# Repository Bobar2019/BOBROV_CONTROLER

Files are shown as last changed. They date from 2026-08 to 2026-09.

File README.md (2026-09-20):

# BOB-CONTROL — Firmware ESP32-S3 pour ROV



Firmware temps réel embarqué sur **ESP32-S3** pour le contrôle basse couche du sous-marin **BOB-ROV**.

## Matériel

- **MCU :** ESP32-S3 (PlatformIO, Arduino Core, FreeRTOS)
- **IMU :** BNO085 (`0x4A`) via Adafruit BNO08x (protocole SH-2 — Rotation Vector 9-DOF, montage remappé à la source)
- **PWM :** PCA9685 (16 canaux, 50 Hz)
- **Propulseurs :** 8 × ESC brushless (M1-M4 horizontaux, M5-M8 verticaux)
- **Capteurs :** 3 × INA226 (wattmètres), MS5803/MS5837 (pression/profondeur)
- **Liaison :** RPi 5 via USB-CDC natif ou UART GPIO (921 600 bauds)

## Fonctionnalités

- **Protocole binaire** RPi 5 ↔ ESP32-S3 avec CRC16-CCITT et watchdog failsafe
- **Assistances superposables** (masque de bits, protocole v1.4.0) avec PID 4 axes et mixage différentiel :
  - `0x01` **Auto R/T** — Stabilisation PID du roulis et du tangage sur M5-M8
  - `0x02` **Tenue de Profondeur** — PID altitude (profondeur capturée à l'activation)
  - `0x04` **Auto Cap** — PID lacet sur M1-M4 (cap capturé à l'activation)
  - `0x08` **Retour Surface** — Prioritaire : verticaux vers la surface
  - Combinaisons libres (ex. `0x03` = Auto R/T + profondeur ; `0x07` ≡ ancien AUTO FULL) ; le champ `status` de la télémétrie confirme les boucles réellement actives
- **Interface Web embarquée** (LittleFS) avec portail captif automatique
- **WebSocket temps réel** : télémétrie IMU, pression, PWM, puissance (20 Hz)
- **API REST** : configuration Wi-Fi, I2C, PID, mode série
- **Instruments aviation** : horizon artificiel + HSI (Canvas 2D, lissage LERP)
- **Modèle 3D temps réel** : ROV animé par l'IMU (three.js r128 local, GLB servi depuis LittleFS)
- **Mode Témoin (Dry-Run)** : sorties physiques neutralisées pour banc de test
- **Gestion de priorité** : RPi 5 maître absolu < 1s, sinon bascule Web ESP32

## Build & Flash

```bash
# Compiler
pio run

# Téléverser firmware
pio run -t upload

# Téléverser fichiers Web (LittleFS)
pio run -t uploadfs

# Moniteur série debug
pio device monitor -b 115200
```

## Accès Interface Web

Connectez-vous au point d'accès Wi-Fi **BOB-CONTROL_AP** (mot de passe : `bobrov2026`), puis ouvrez `http://192.168.4.1`.

## Documentation

- [PROTOCOLE_RPI5.md](PROTOCOLE_RPI5.md) — protocole série RPi 5 ↔ ESP32-S3 : trames octet par octet, sémantique des statuts, exemple Python prêt à l'emploi, vecteurs de test.
- [BOBCONTROL.md](BOBCONTROL.md) pour la spécification complète (protocole série, architecture, brochage, API).

## Licence

MIT

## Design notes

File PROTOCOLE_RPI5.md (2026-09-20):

# Protocole de Communication Série — BOB-CONTROL ↔ Raspberry Pi 5

**Auteur :** DERO DIDIER — [ddero2014@gmail.com](mailto:ddero2014@gmail.com)
**Cible :** Cockpit RPi 5 (BOB-ROV) — développement Python / pyserial
**Objet :** Spécification complète du lien binaire série entre le Raspberry Pi 5 et le firmware **BOB-CONTROL** (ESP32-S3). Ce document contient tout le nécessaire pour écrire le code côté RPi 5 sans jamais ouvrir le firmware : format des trames octet par octet, sémantique exacte des champs, comportements de sécurité, exemple Python prêt à l'emploi et vecteurs de test.

---

## 1. Vue d'ensemble

| Élément | Valeur |
| :--- | :--- |
| Topologie | Liaison point à point RPi 5 ↔ ESP32-S3 (full-duplex) |
| Débit | **921 600 bauds**, 8 bits, sans parité, 1 stop (8N1) |
| Trames | **Tailles fixes** — descendante : **40 octets** ; montantes : **73 octets** (télémétrie) et **27 octets** (configuration des noms, §5.6) |
| Intégrité | **CRC16-CCITT-FALSE** (polynôme `0x1021`, init `0xFFFF`) sur chaque trame |
| Trame descendante | 20–50 Hz recommandé (commande : masque d'assistances, armement, 16 consignes PWM, masque GPIO ON/OFF) |
| Trame montante | **100 Hz fixe** (télémétrie : IMU, pression, température, puissance, PWM, état des sorties ON/OFF) |
| Synchronisation | Requête descendante `0xFF` (§4.4) ⇒ l'ESP32 renvoie les **noms personnalisés** des sorties (rafale de 10 trames de **27 octets**, §5.6). Aussi poussée automatiquement à la première commande reçue après (re)connexion, et après chaque modification via l'interface Web |
| Sorties ON/OFF | 4 sorties numériques (GPIO 15/16/17/18 par défaut) pilotées par `gpio_cmd`, état réel dans `gpio_state` — forcées à OFF sur watchdog ou E-Stop |
| Failsafe | Watchdog **500 ms** par défaut : perte de liaison ⇒ tous les actionneurs à leur position de sécurité + 4 sorties ON/OFF à OFF |
| Endianness | Tous les champs multi-octets en **little-endian**, **sauf le CRC** (big-endian) |

**Principe de fonctionnement côté RPi 5 :** le Pi envoie en continu des trames de commande (au moins toutes les 400 ms pour ne pas déclencher le watchdog) et lit en continu les trames de télémétrie qui arrivent à 100 Hz. Le firmware applique les consignes, ou bascule automatiquement en sécurité si le flux s'interrompt.

---

## 2. Liaison physique — deux interfaces au choix

Le firmware embarque **deux interfaces physiques** pour le protocole binaire. Le choix se fait dans l'onglet **Paramètres** de l'interface Web de l'ESP32 et est mémorisé en NVS (**redémarrage nécessaire** après changement).

| Mode | Côté ESP32-S3 | Côté RPi 5 | Particularités |
| :--- | :--- | :--- | :--- |
| **USB-CDC Natif** (défaut) | Port USB-C | `/dev/ttyACM0` | Le debug texte du firmware **partage le même port** : la télémétrie binaire est entrecoupée de messages `[SERIAL]`, `[SENSORS]`… Le parseur doit être tolérant (voir §7) ou filtrer sur les en-têtes. |
| **UART Matériel** | `Serial1` — RX : **GPIO 1**, TX : **GPIO 2** | `/dev/serial0` (ou `/dev/ttyAMA0`) | Lien dédié, **propre** (aucun texte parasite). Câblage croisé obligatoire : TX du Pi → GPIO 1, GPIO 2 → RX du Pi. Référence commune (GND) indispensable. |

> **Note RPi 5 (mode UART) :** activer l'UART matériel via `raspi-config` → *Interface Options* → *Serial Port* : **login shell = NON**, **matériel série = OUI**. Vérifier aussi que `/boot/firmware/config.txt` contient `enable_uart=1`.
>
> **Permissions :** ajouter l'utilisateur au groupe `dialout` (`sudo usermod -aG dialout $USER`, puis reconnexion) pour accéder au port sans `sudo`.

---

## 3. Cadre général des trames

### 3.1 En-têtes et sens de circulation

| Sens | En-tête (2 octets) | Type (offset 2) | Taille totale |
| :--- | :--- | :--- | :--- |
| RPi 5 → ESP32-S3 (descendante) | `0xAA` `0x55` | `0x01` | **40 octets** |
| RPi 5 → ESP32-S3 (descendante) | `0xAA` `0x55` | `0xFF` | **40 octets** — requête de synchronisation, contenu ignoré (§4.4) |
| ESP32-S3 → RPi 5 (montante) | `0x55` `0xAA` | `0x02` | **73 octets** |
| ESP32-S3 → RPi 5 (montante) | `0x55` `0xAA` | `0x03` | **27 octets** — nom d'un canal PWM auxiliaire 10–15 (§5.6) |
| ESP32-S3 → RPi 5 (montante) | `0x55` `0xAA` | `0x04` | **27 octets** — nom d'une sortie tout-ou-rien 1–4 (§5.6) |

Les en-têtes ont des motifs **opposés** (`AA 55` vs `55 AA`) : un simple `find` sur la séquence correcte suffit à se resynchroniser dans un flux bruité.

### 3.2 CRC16-CCITT-FALSE

Le CRC couvre les octets **de l'offset 2 jusqu'à l'avant-dernier octet de la trame** (le champ CRC lui-même est exclu) :

| Trame | Octets couverts par le CRC | CRC stocké aux offsets |
| :--- | :--- | :--- |
| Descendante (40 octets) | `[2..37]` | `[38]` = octet **fort**, `[39]` = octet **faible** |
| Montante (73 octets) | `[2..70]` | `[71]` = octet **fort**, `[72]` = octet **faible** |
| Configuration des noms (27 octets) | `[2..24]` | `[25]` = octet **fort**, `[26]` = octet **faible** |

Paramètres : polynôme `0x1021`, valeur initiale `0xFFFF`, ni réflexion d'entrée/sortie, ni XOR final.
**Valeur de contrôle** : `crc16_ccitt(b"123456789") == 0x29B1`.

> **⚠️ Le CRC est stocké en big-endian** (octet fort d'abord), contrairement à **tous** les autres champs multi-octets de la trame qui sont en little-endian. C'est la source d'erreur n°1 des implémentations tierces — voir l'exemple validé §7.

### 3.3 Résynchronisation

Une trame descendante invalide (CRC KO) est **silencieusement ignorée** par le firmware : la machine à états repart en attente d'en-tête. Côté RPi 5, appliquer la même stratégie : chercher `0x55 0xAA`, tenter de décoder la trame, en cas de CRC invalide **avancer d'un seul octet** et recommencer (jamais sauter la trame d'un bloc).

**Depuis la v1.5.0, la trame montante n'a plus une taille unique** : la longueur attendue se déduit du **type à l'offset 2** — `0x02` ⇒ 73 octets, `0x03`/`0x04` ⇒ 27 octets, tout autre octet ⇒ faux en-tête, avancer d'un octet (voir la classe `UplinkReader` du §7).

---

## 4. Trame descendante — RPi 5 → ESP32-S3 (40 octets)

Format : `[0xAA][0x55][TYPE][MODE][ARM][PWM_0..15][GPIO_CMD][CRC_HI][CRC_LO]`

| Offset | Taille | Champ | Type | Valeurs | Description |
| ---: | ---: | :--- | :--- | :--- | :--- |
| 0 | 1 | `header1` | `uint8_t` | `0xAA` | En-tête 1 |
| 1 | 1 | `header2` | `uint8_t` | `0x55` | En-tête 2 |
| 2 | 1 | `type` | `uint8_t` | `0x01` | Type « commande » |
| 3 | 1 | `mode` | `uint8_t` | masque de bits | **Masque d'assistances superposables** (v1.4.0) — chaque bit active une boucle indépendante : bit 0 (`0x01`) = Auto Roulis/Tangage, bit 1 (`0x02`) = Tenue de Profondeur, bit 2 (`0x04`) = Auto Cap (Yaw), bit 3 (`0x08`) = Retour Surface (**prioritaire**). `0x00` = Passif (manuel direct). Exemple : `0x03` = Auto R/T + Tenue de Profondeur. Bits 4–7 ignorés. |
| 4 | 1 | `arm_state` | `uint8_t` | `0` `1` `2` | **0** = Désarmé, **1** = Armé, **2** = E-Stop (arrêt d'urgence) |
| 5 | 32 | `pwm[0..15]` | `uint16_t` × 16 (LE) | 1000–2000 | Consignes en **µs**. `pwm[k]` occupe les offsets `5 + 2k` (octet faible d'abord) : `pwm[0]` @ 5–6 … `pwm[15]` @ 35–36. Neutre : **1500**. Le firmware borne toute valeur à 1000–2000 µs. |
| 37 | 1 | `gpio_cmd` | `uint8_t` | masque 4 bits | Commandes des 4 sorties tout-ou-rien : **bit 0 = sortie 1** … **bit 3 = sortie 4** (1 = ON, 0 = OFF). Bits 4–7 ignorés. Les sorties sont pilotables **même désarmé** (auxiliaires) ; neutralisées à OFF par l'E-Stop et le watchdog. |
| 38 | 1 | `crc16_hi` | `uint8_t` | — | CRC16 (voir §3.2) — octet fort |
| 39 | 1 | `crc16_lo` | `uint8_t` | — | CRC16 — octet faible |

> **Composition des assistances (v1.4.0) :** le champ `mode` est un masque — les boucles PID se superposent librement (ex. `0x03` = Auto R/T + tenue de profondeur). À l'activation d'une tenue, la consigne est capturée sur place : **profondeur courante** pour le bit 1, **cap courant** pour le bit 2. Le **bit 3 (Retour Surface) est prioritaire** : il suspend l'Auto R/T et la tenue de profondeur et force les moteurs verticaux M5–M8 vers la surface (≈ 1700 µs) ; l'Auto Cap (bit 2) reste actif sur les horizontaux M1–M4.

### 4.1 Affectation des 16 canaux

| Canal | Actionneur | Plage utile | Neutre / repos |
| :--- | :--- | :--- | :--- |
| 0–7 | ESC propulseurs M1–M8 (M1–M4 horizontaux, M5–M8 verticaux) | 1000–2000 µs | 1500 µs |
| 8–9 | Servomoteurs Pan & Tilt caméra | 1000–2000 µs | 1500 µs |
| 10–11 | Pince / rotation d'outil | 1000–2000 µs | 1500 µs |
| 12–13 | Gradateurs MOSFET projecteurs LED | 1000 µs = 0 % → 2000 µs = 100 % | 1000 µs (0 %) |
| 14–15 | Canaux auxiliaires / extensions | 1000–2000 µs | 1500 µs |

> **Depuis le protocole v1.1.0**, les canaux 10 à 15 sont **typables individuellement** (Bidirectionnel / Unidirectionnel), configurables dans l'onglet Paramètres de l'interface Web et persistés en NVS — voir §4.3.

### 4.2 Cadence et comportement d'émission

* **Envoyer en continu**, même quand rien ne change : c'est ce flux qui alimente le watchdog (§6.1) et le statut « maître » (§6.3).
* Cadence recommandée : **20 à 50 trames/s** (une trame toutes les 20–50 ms). À 100 Hz, aucune contre-indication technique, seulement de la bande passante inutile.
* En cas de coupure, le failsafe s'active après le **timeout watchdog (500 ms par défaut)** : prévoir un envoi toutes les 400 ms *au pire* si l'application est chargée.

### 4.3 Typage des canaux 10–15 (Bidirectionnel / Unidirectionnel)

Chaque canal 10 à 15 est configurable **individuellement** depuis l'onglet Paramètres de l'interface Web (ressource NVS, appliqué à chaud — aucun redémarrage requis) :

| Type | Plage des consignes | Position de sécurité (failsafe / E-Stop / watchdog) |
| :--- | :--- | :--- |
| **Bidirectionnel** | 1000–2000 µs, neutre 1500 µs | **1500 µs** |
| **Unidirectionnel** (pleine échelle) | 1000 µs = 0 % → 2000 µs = 100 % | **1000 µs (0 %)** |

Configuration par défaut : CH10/11 (pinces/outils) et CH14/15 (auxiliaires) en **Bidirectionnel**, CH12/13 (gradateurs LED) en **Unidirectionnel**. Le firmware borne toujours les consignes à 1000–2000 µs quel que soit le type ; le type ne change que la **position de sécurité** appliquée par le failsafe (et l'affichage côté interface Web).

### 4.4 Requête de synchronisation — type `0xFF` (v1.5.0)

Trame descendante de **40 octets** au **format identique** à la commande standard (§4) — seul le champ `type` vaut `0xFF`. **Tout le contenu (offsets 3 à 37) est ignoré** : envoyer des zéros suffit (CRC calculé normalement sur `[2..37]`).

Effets à la réception côté firmware :

* l'ESP32 renvoie immédiatement les **noms personnalisés** des sorties (rafale de trames montantes `0x03`/`0x04`, §5.6) — **sans modifier** les consignes en cours (PWM, GPIO, armement) ;
* la trame **réarme le watchdog** (elle vaut preuve de liaison, comme une commande valide) et efface le bit `0x08` de la télémétrie.

**À envoyer par le cockpit :**

1. **au démarrage** (avant la première trame de commande) — le cockpit récupère les libellés des sorties avant d'afficher quoi que ce soit ;
2. après toute **reprise de liaison** — en pratique redondant : le firmware resynchronise déjà automatiquement à la première commande reçue après (re)connexion (§5.6.2), mais l'envoi explicite est inoffensif.

> Le firmware renvoie **toujours la configuration complète** (6 canaux PWM + 4 sorties TOR, 10 trames), que des noms soient personnalisés ou non : une trame à `name_len = 0` signifie « nom par défaut » — le RPi 5 applique alors son propre libellé.

---

## 5. Trame montante — ESP32-S3 → RPi 5 (73 octets)

Format : `[0x55][0xAA][TYPE][STATUS][QUAT][GYRO][PRESS][TEMP][POWER×6][PWM_ACT×16][GPIO_STATE][CRC]`

Émise **en continu à 100 Hz** (toutes les 10 ms) dès que le firmware a démarré.

| Offset | Taille | Champ | Type | Facteur de conversion | Description |
| ---: | ---: | :--- | :--- | :--- | :--- |
| 0 | 1 | `header1` | `uint8_t` | — | `0x55` |
| 1 | 1 | `header2` | `uint8_t` | — | `0xAA` |
| 2 | 1 | `type` | `uint8_t` | — | `0x02` (télémétrie) |
| 3 | 1 | `status` | `uint8_t` | bits — voir §5.1 | État du système |
| 4 | 8 | `quat[4]` | `int16_t` × 4 (LE) | **÷ 10 000** | Quaternion W, X, Y, Z du repère **véhicule** (voir §5.3) |
| 12 | 6 | `gyro[3]` | `int16_t` × 3 (LE) | **÷ 100** → °/s | Vitesses angulaires X, Y, Z du repère véhicule |
| 18 | 4 | `pressure` | `int32_t` (LE) | **÷ 10** → mbar | Pression absolue (ex. 10132 = 1013,2 mbar) |
| 22 | 4 | `temperature` | `int32_t` (LE) | **÷ 100** → °C | Température de l'eau (ex. 2500 = 25,00 °C) |
| 26 | 12 | `power[6]` | `uint16_t` × 6 (LE) | **÷ 1000** → V / A | Énergie propulsion (v1.1.0) : `[V_BAT, rés, signal_H, I_H, signal_V, I_V]` en mV / mA — voir §5.2 |
| 38 | 32 | `pwm_actual[16]` | `uint16_t` × 16 (LE) | µs (entiers) | Consignes PWM courantes. `pwm_actual[k]` occupe les offsets `38 + 2k`. |
| 70 | 1 | `gpio_state` | `uint8_t` | masque 4 bits — voir §5.5 | État **réel relu** des 4 sorties ON/OFF : bit 0 = sortie 1 … bit 3 = sortie 4 (1 = ON) |
| 71 | 2 | `crc16` | `uint16_t` (**BE**) | — | CRC16 sur `[2..70]` — octet fort puis faible |

### 5.1 Sémantique exacte des bits de `status`

| Bit | Masque | Signification réelle (comportement du firmware) |
| :--- | :--- | :--- |
| 0 | `0x01` | Réservé (toujours 0) |
| 1 | `0x02` | **Liaison établie** : positionné dès qu'**au moins une trame descendante valide a été reçue depuis le boot**. ⚠️ Ce n'est **pas** l'état d'armement courant — c'est un témoin de liaison (« le firmware a déjà entendu le RPi 5 »). |
| 2 | `0x04` | **Auto Roulis/Tangage réellement actif** (v1.4.0) : boucle PID roulis + tangage en cours d'exécution — 0 si la boucle est absente du masque ou **suspendue par le retour surface**. |
| 3 | `0x08` | **Watchdog série déclenché** : plus aucune trame descendante valide reçue depuis > timeout (défaut 500 ms). Redescend automatiquement dès qu'une trame valide arrive. |
| 4 | `0x10` | **Dry-run (Mode Témoin)** : sorties physiques PCA9685 neutralisées (les consignes sont mémorisées dans `pwm_actual` mais aucune impulsion n'est émise vers les actionneurs). |
| 5 | `0x20` | **Tenue de Profondeur réellement active** (v1.4.0) : boucle PID altitude en cours d'exécution — 0 si absente du masque ou **suspendue par le retour surface**. |
| 6 | `0x40` | **Auto Cap réellement actif** (v1.4.0) : boucle PID lacet en cours d'exécution (indépendante du retour surface). |
| 7 | `0x80` | **Retour Surface réellement actif** (v1.4.0) : verticaux M5–M8 forcés vers la surface, Roll/Pitch et tenue de profondeur suspendus. |

### 5.2 Détail des 6 mesures de puissance (v1.1.0 — INA3221)

**Sémantique v1.1.0 :** l'INA3221 (triple mesure, `0x40`) remplace le premier INA226 et supervise l'énergie de propulsion. **Le format binaire est inchangé** (mêmes 6 slots mV/mA, mêmes offsets) — seule la sémantique des valeurs change :

| Index `power` | Offset | Mesure | Source (bus I2C n°1) |
| :--- | ---: | :--- | :--- |
| `power[0]` | 26 | **Tension batterie propulsion V_BAT** (mV) | **INA3221** (`0x40`) canal 1 |
| `power[1]` | 28 | Réservé (**0**) | INA3221 canal 1 — pas de shunt sur ce canal |
| `power[2]` | 30 | Signal brut capteur horizontaux (mV) | INA3221 canal 2 — tension ACS770 lue sur IN- |
| `power[3]` | 32 | **Courant propulseurs horizontaux M1–M4** (mA) | **ACS770-100U** via INA3221 canal 2 (40 mV/A) |
| `power[4]` | 34 | Signal brut capteur verticaux (mV) | INA3221 canal 3 — tension ACS770 lue sur IN- |
| `power[5]` | 36 | **Courant propulseurs verticaux M5–M8** (mA) | **ACS770-100U** via INA3221 canal 3 (40 mV/A) |

* Le courant est émis en valeur **absolue** (mA) ; plage utile **±4,09 A** (au-delà, l'ACS770 sature — le firmware le traite comme un défaut de surintensité). Capteur absent ⇒ 0.
* Les champs `power[2]` / `power[4]` (signal brut mV) sont fournis pour diagnostic — le firmware applique déjà la conversion en Ampères dans `power[3]` / `power[5]`.
* Les deux **INA226 résiduels** (#2 Aux/LEDs `0x44`, #3 `0x45`) ne transitent **pas** dans la trame série : ils restent visibles uniquement dans la télémétrie WebSocket de l'interface Web embarquée (`power[3]` / `power[4]` du JSON).
* Ancienne sémantique (firmware ≤ v1.0.1) : `[V,I]` du Pi, Aux et Moteurs — un récepteur ignorant la version décodait 3 wattmètres.

### 5.3 Repère IMU et conversions complémentaires

Le quaternion et le gyroscope sont exprimés dans le **repère véhicule** (NED : **X = avant**, **Y = droite**, **Z = bas**), montage du BNO085 déjà compensé par le firmware. Le quaternion est **unitaire** : `w² + x² + y² + z² = 1` (tolérance numérique).

Conversions utiles pour l'affichage (formules identiques à celles du firmware) :

\[
\begin{aligned}
\text{roll} &= \operatorname{atan2}\big(2(wx+yz),\; 1-2(x^2+y^2)\big) \\
\text{pitch} &= \operatorname{asin}\big(2(wy-zx)\big) \\
\text{cap} &= -\operatorname{atan2}\big(2(wz+xy),\; 1-2(y^2+z^2)\big)
\end{aligned}
\]

Angles en radians, cap positif dans le sens **horaire** (nord → est). Normaliser le cap dans \([-180°, +180°]\) ou \([0°, 360°]\) selon usage.

Profondeur (le firmware n'envoie que la pression absolue ; à convertir côté RPi 5) :

* **Profondeur eau douce (m)** : \(h = \Delta P_{mbar} \times 100 / (\rho \cdot g) \approx \Delta P_{mbar} \times 0{,}010194\) avec \(\Delta P = P - P_{surface}\), \(\rho = 1000\ \text{kg/m}^3\), \(g = 9{,}81\ \text{m/s}^2\).
* **Altitude barométrique (m, hors de l'eau)** : \(h = 44330 \times \left(1 - (P/P_0)^{0,190284}\right)\) avec \(P_0 = 1013{,}25\) mbar (à adapter à la pression du jour).
* La référence surface \(P_{surface}\) se capture **capteur hors de l'eau au démarrage** — c'est à l'application RPi 5 de mémoriser sa propre tare (les données brutes reçues restent absolues).

### 5.4 `pwm_actual` — consignes vs sorties physiques

`pwm_actual` reflète **les consignes courantes appliquées au contrôleur PWM** (après clamp 1000–2000 µs et, en mode AUTO, après corrections PID et mixage) — et non l'état électrique des sorties :

* Si `status & 0x10` (**dry-run**) : les valeurs affichées sont mémorisées mais **aucune sortie physique** n'est pilotée (le PCA9685 reste au neutre).
* Si `status & 0x08` (**watchdog**) : les sorties ont été forcées à leur position de sécurité ; `pwm_actual` peut encore montrer les dernières consignes jusqu'à la trame suivante.

### 5.5 `gpio_state` — état réel des 4 sorties ON/OFF

`gpio_state` reflète l'état **physiquement relu** des 4 sorties tout-ou-rien (niveau des broches après écriture) — et non la dernière commande reçue. Si `gpio_cmd` (trame descendante) et `gpio_state` diffèrent durablement, la commande n'a pas pu être appliquée.

* **Watchdog déclenché** (`status & 0x08`) : les 4 sorties sont forcées **à OFF** ⇒ `gpio_state = 0x00`.
* **E-Stop** (`arm_state = 2`) : idem, `gpio_state = 0x00`.
* Les broches sont assignées par défaut à **GPIO 15/16/17/18** (reconfigurables dans l'onglet Paramètres de l'interface Web, appliquées au redémarrage) et initialisées **à OFF** au boot.
* Les sorties ON/OFF sont indépendantes du **dry-run** (§6.4) : le dry-run ne concerne que les sorties PWM/PCA9685.

### 5.6 Trames de configuration des noms — types `0x03` / `0x04` (v1.5.0)

**Source unique de vérité :** l'ESP32-S3 détient les **noms personnalisés** des sorties (saisis dans l'interface Web, persistés en NVS) et les transmet au RPi 5 — le cockpit n'a **aucune valeur codée en dur** : il affiche les libellés reçus, ou son propre libellé par défaut quand `name_len = 0`.

#### 5.6.1 Format — 27 octets par sortie

Format : `[0x55][0xAA][TYPE][ID][LEN][NAME ×20][CRC_HI][CRC_LO]`

| Offset | Taille | Champ | Type | Valeurs | Description |
| ---: | ---: | :--- | :--- | :--- | :--- |
| 0 | 1 | `header1` | `uint8_t` | `0x55` | En-tête 1 |
| 1 | 1 | `header2` | `uint8_t` | `0xAA` | En-tête 2 |
| 2 | 1 | `type` | `uint8_t` | `0x03` `0x04` | `0x03` = nom d'un canal PWM auxiliaire (10–15) ; `0x04` = nom d'une sortie tout-ou-rien |
| 3 | 1 | `id` | `uint8_t` | 10–15 / 1–4 | Numéro de **canal PWM** (`0x03`) ou de **sortie TOR** (`0x04`) — voir §5.6.3 |
| 4 | 1 | `name_len` | `uint8_t` | 0–20 | Longueur **utile** du nom en octets UTF-8. **0 = nom par défaut** (le RPi 5 applique son libellé par défaut) |
| 5 | 20 | `name` | `char[20]` | UTF-8 | Nom, complété par des `0x00` au-delà de `name_len` — lire exactement `name_len` octets |
| 25 | 1 | `crc16_hi` | `uint8_t` | — | CRC16 sur `[2..24]` — octet **fort** |
| 26 | 1 | `crc16_lo` | `uint8_t` | — | CRC16 — octet **faible** |

#### 5.6.2 Déclencheurs d'envoi (comportement du firmware)

Les **10 trames** (6 PWM + 4 TOR) sont émises en **rafale lissée** : **une trame par cycle de télémétrie (10 ms)**, intercalée entre deux trames `0x02` complètes — la cadence de télémétrie **100 Hz reste intacte**. La rafale complète s'étale sur ~100 ms.

| Déclencheur | Quand |
| :--- | :--- |
| **Requête `0xFF`** | À réception de la trame descendante `0xFF` (§4.4) — cas nominal au démarrage du cockpit |
| **Première commande après (re)connexion** | À la première trame `0x01` valide reçue après le boot de l'ESP32 **ou** après un déclenchement du watchdog — le cockpit reçoit les noms même s'il n'émet jamais de requête `0xFF` |
| **Modification dans l'interface Web** | À chaque sauvegarde des noms (`POST /api/names`) — mise à jour du cockpit en temps réel, sans redémarrage |

#### 5.6.3 Sémantique des `id`

| `type` | `id` | Sortie concernée |
| :--- | :--- | :--- |
| `0x03` | 10–15 | Canaux PWM auxiliaires 10 à 15 (pinces/outils, gradateurs, auxiliaires — voir §4.1) |
| `0x04` | 1–4 | Sorties tout-ou-rien 1 à 4 (**id = bit + 1**, cohérent avec `gpio_cmd`/`gpio_state` §4/§5.5) |

Les canaux **0 à 9** (propulseurs M1–M8, servos caméra) ne sont **pas** transmis : ce sont des affectations fixes du véhicule.

#### 5.6.4 Traitement recommandé côté RPi 5

* **Au démarrage** : envoyer `build_sync_request()` (§7), puis émettre les commandes normales ; attendre la rafale (~100 ms) avant d'afficher les libellés.
* **À chaud** : chaque trame `0x03`/`0x04` remplace le libellé de la sortie `id` — appliquer immédiatement, sans redémarrer.
* `name_len = 0` ⇒ appliquer votre libellé par défaut. Nota : le **pilotage** utilise toujours `id`/masques (`gpio_cmd`, index PWM) — jamais le nom `name`.

---

## 6. Comportements du firmware (règles de sécurité et de priorité)

### 6.1 Watchdog série — failsafe 500 ms

* Le firmware attend **au moins une trame descendante valide** dans une fenêtre de **500 ms** (défaut, réglable 100 ms–plusieurs s dans l'onglet Paramètres via NVS — clé `serial_timeout`).
* Dépassement ⇒ **tous les canaux PWM forcés à leur position de sécurité** (1500 µs pour les bidirectionnels, 1000 µs / 0 % pour les unidirectionnels) et **les 4 sorties ON/OFF forcées à OFF** (`gpio_state = 0x00`). Bit `0x08` positionné dans la télémétrie.
* Dès qu'une trame valide arrive : le watchdog est réarmé, le bit `0x08` disparaît, et **les consignes de cette trame sont appliquées au cycle suivant (≤ 10 ms)**.
* Au démarrage du firmware : le watchdog **ne se déclenche pas** tant qu'aucune trame n'a jamais été reçue (les sorties restent de toute façon en dry-run/neutre par défaut).

### 6.2 États d'armement (champ `arm_state`)

| `arm_state` | Effet immédiat à la réception de CHAQUE trame |
| :--- | :--- |
| **0 — Désarmé** | Canaux **0–7 forcés au neutre** (1500 µs). Canaux **8–15 acceptés tels quels** (pan/tilt, pince, gradateurs utilisables désarmé). Les **4 sorties ON/OFF restent pilotables** (`gpio_cmd` appliqué — auxiliaires utilisables désarmé). Reset des PID. |
| **1 — Armé** | **Les 16 canaux** sont appliqués (`pwm[0..15]`) ainsi que le **masque `gpio_cmd`**. Le **masque d'assistances** est appliqué (superposition Auto R/T, tenue de profondeur, Auto Cap, retour surface). Le contrôleur de vol considère le RPi 5 comme maître. |
| **2 — E-Stop** | **Tous** les canaux à leur position de sécurité (1500 µs / 0 %) + **les 4 sorties ON/OFF forcées à OFF** + reset des PID. Priorité absolue, appliqué à chaque trame reçue. |

> **Point opérationnel :** seules les trames **ARMÉES** transmettent le `mode` et rafraîchissent la maîtrise du RPi 5 (§6.3). Pour reprendre la main après un long arrêt, il suffit de renvoyer des trames armées.

### 6.3 Priorité « maître » RPi 5 / interface Web ESP32

* Chaque trame **armée** reçue marque le RPi 5 comme **maître** du contrôleur de vol.
* Après **1000 ms sans trame armée**, le firmware repasse en mode manuel ESP32 (l'interface Web peut alors changer le mode ; journal série : `[FLIGHT] Maître → Manuel ESP32 (timeout RPi 5)`).
* Tant que le RPi 5 est maître, toute commande de mode émise par l'interface Web est **ignorée** (journal : `[FLIGHT] Commande Web ignorée — RPi 5 est maître`).
* Conséquence pratique : **envoyer des trames armées en continu** (c'est le cas nominal à 20–50 Hz) pour rester maître.

### 6.4 Mode Dry-Run (Sorties Matérielles)

Au boot, les sorties physiques sont **neutralisées** (dry-run actif, bit `0x10`). Les consignes reçues sont suivies dans `pwm_actual` mais le PCA9685 n'émet rien. L'activation des sorties réelles se fait **uniquement** depuis l'interface Web (bouton « Sorties Matérielles », WebSocket `{output_enable: true}` ou REST `POST /api/pwm/output-enable`). C'est un garde-fou de banc : le RPi 5 ne peut pas le désactiver à distance.

> **Sorties ON/OFF :** le dry-run ne les concerne pas — les 4 GPIO sont des sorties numériques à part entière, initialisées à OFF au boot puis pilotables par `gpio_cmd` (et forcées à OFF par le watchdog et l'E-Stop, voir §5.5).

### 6.5 Redémarrage automatique du firmware (perte définitive de l'IMU)

Le firmware embarque un **watchdog IMU** dédié au BNO085 (capteur d'attitude, seul sur le bus I2C n°1). Si le flux de quaternions se fige en opération (plongée, longue inactivité), la récupération escalade automatiquement en 3 niveaux :

1. **Reprise douce SH-2** — après 1 s sans quaternion : ré-initialisation logicielle du capteur (réécriture des rapports SH-2) ;
2. **Reset matériel du bus I2C** — si le niveau 1 échoue ou si le contrôleur I2C reste bloqué (`ESP_ERR_INVALID_STATE`) : destruction puis recréation de l'instance `Adafruit_BNO08x`, 9 impulsions SCL + condition STOP (bit-bang), réinitialisation complète de `Wire` ;
3. **Redémarrage contrôlé** — si le capteur (qui **a déjà fonctionné depuis le boot**) ne répond toujours pas après **3 tentatives de niveau 2** ou **8 s sans aucun quaternion** : le firmware force **tous les canaux PWM à leur position de sécurité** (1500 µs, 0 % pour les unidirectionnels), émet un log explicite sur le moniteur série, puis déclenche `esp_restart()` — **redémarrage automatique de l'ESP32**.

**Ce que le RPi 5 doit savoir :**

* **Propulsion au neutre pendant toute la phase de récupération (niveaux 1 & 2)** : dès le 1er échec, les canaux 0-7 sont verrouillés à 1500 µs **à chaque cycle de contrôle** — une consigne armée réappliquée entre deux tentatives ne peut jamais faire repartir la propulsion avec une attitude inconnue. Les canaux 8-15 (servos, pince, gradateurs) restent pilotables.
* **Pendant le redémarrage (~2-3 s)** : la télémétrie est interrompue, **mais les propulseurs restent physiquement au neutre** — le PCA9685 est un générateur autonome qui conserve ses registres pendant le reboot de l'ESP32 (neutre maintenu sans aucune intervention). Les trames descendantes émises pendant cette fenêtre sont simplement perdues.
* **Après le redémarrage** : la télémétrie reprend seule. Le bit **liaison établie (`0x02`) repasse à 0 puis à 1** dès la première trame descendante valide reçue, et les sorties repartent en **dry-run (`0x10` = 1)** — comme à chaque boot, la réactivation des sorties réelles redevient une action manuelle dans l'interface Web.
* **Aucune action spécifique n'est requise côté RPi 5** : continuer à émettre normalement (la cadence 20-50 Hz ré-établit liaison et maîtrise automatiquement).

> **Garde-fou anti-boucle :** ce redémarrage ne se produit que si le capteur **a déjà fourni au moins un quaternion depuis le boot**. Un BNO085 jamais détecté ou jamais fonctionnel au démarrage n'est **jamais** redémarré en boucle : il reste en mode espacé (badge rouge, une tentative complète toutes les 30 s) et la propulsion demeure au neutre par défaut.

---

## 7. Exemple Python complet (validé hors ligne)

Code autonome, sans dépendance autre que **pyserial** (`pip install pyserial`). Toutes les fonctions de décodage ont été vérifiées contre les vecteurs de test du §8.

```python
#!/usr/bin/env python3
"""Cockpit minimal BOB-ROV — liaison binaire avec BOB-CONTROL (ESP32-S3).
Télémétrie 100 Hz + synchronisation des noms de sorties au démarrage."""
import struct
import time
import serial

# ==================== Constantes du protocole ====================

PORT = '/dev/ttyACM0'      # USB-CDC natif  |  UART GPIO : '/dev/serial0'
BAUD = 921600
TX_HZ = 25.0               # cadence descendante recommandée : 20-50 Hz

# Mode = masque d'assistances superposables (v1.4.0) — combiner avec |
MODE_PASSIF = 0x00
MODE_RT, MODE_DEPTH, MODE_CAP, MODE_SURFACE = 0x01, 0x02, 0x04, 0x08

ARM_DISARMED, ARM_ARMED, ARM_ESTOP = 0, 1, 2

STATUS_ARMED, STATUS_RT, STATUS_WDG, STATUS_DRYRUN = 0x02, 0x04, 0x08, 0x10
STATUS_DEPTH, STATUS_CAP, STATUS_SURFACE = 0x20, 0x40, 0x80

# Trames (v1.5.0) : type à l'offset 2 + taille fixe associée
UL_TELEMETRY, UL_CFG_PWM, UL_CFG_GPIO = 0x02, 0x03, 0x04
DL_SYNC = 0xFF             # requête de synchronisation (descendante, 40 octets)
FRAME_SIZES = {UL_TELEMETRY: 73, UL_CFG_PWM: 27, UL_CFG_GPIO: 27}

# ==================== CRC16-CCITT-FALSE ====================

def crc16_ccitt(data: bytes) -> int:
    """CRC16-CCITT-FALSE : poly 0x1021, init 0xFFFF, pas d'inversion.
    Valeur de contrôle : crc16_ccitt(b'123456789') == 0x29B1."""
    crc = 0xFFFF
    for b in data:
        crc ^= b << 8
        for _ in range(8):
            crc = ((crc << 1) ^ 0x1021) & 0xFFFF if (crc & 0x8000) else (crc << 1) & 0xFFFF
    return crc

# ==================== Trame descendante (40 octets) ====================

def build_downlink_frame(mode: int, arm_state: int, pwm_us, gpio_cmd: int = 0) -> bytes:
    """Construit la trame de commande RPi 5 -> ESP32-S3 (40 octets).
    mode : masque d'assistances superposables (MODE_RT | MODE_DEPTH | ...).
    pwm_us : séquence de 16 valeurs en microsecondes (1000-2000).
    gpio_cmd : masque 4 bits des sorties ON/OFF (bit 0 = sortie 1, 1 = ON)."""
    payload = struct.pack('<BBB16HB', 0x01, mode, arm_state, *pwm_us, gpio_cmd)
    crc = crc16_ccitt(payload)                 # CRC sur [2..37]
    return bytes((0xAA, 0x55)) + payload + struct.pack('>H', crc)   # CRC big-endian

def build_sync_request() -> bytes:
    """Requête de synchronisation (40 octets, contenu ignoré par le firmware).
    À envoyer au démarrage du cockpit : l'ESP32 renvoie alors les noms
    personnalisés des sorties (trames montantes 0x03/0x04, voir §5.6)."""
    payload = struct.pack('<B35x', DL_SYNC)    # type 0xFF + 35 octets à zéro
    crc = crc16_ccitt(payload)                 # CRC sur [2..37]
    return bytes((0xAA, 0x55)) + payload + struct.pack('>H', crc)   # CRC big-endian

# ==================== Trame montante (73 octets) ====================

def parse_uplink_frame(frame: bytes) -> dict:
    """Valide et décode une trame de télémétrie (ESP32-S3 -> RPi 5)."""
    if len(frame) != 73:
        raise ValueError(f'trame de {len(frame)} octets (attendu 73)')
    if frame[0] != 0x55 or frame[1] != 0xAA or frame[2] != 0x02:
        raise ValueError('en-tête invalide')
    if (frame[71] << 8 | frame[72]) != crc16_ccitt(frame[2:71]):    # CRC sur [2..70]
        raise ValueError('CRC16 invalide')
    (type_, status, w, x, y, z, gx, gy, gz, pressure, temperature, *rest) = \
        struct.unpack_from('<BB4h3h2i6H16HB', frame, 2)
    return {
        'status': status,
        'armed': bool(status & STATUS_ARMED),      # liaison établie (≥ 1 trame reçue)
        'auto_rt': bool(status & STATUS_RT),       # Auto Roulis/Tangage réellement actif
        'depth_hold': bool(status & STATUS_DEPTH), # tenue de profondeur active
        'cap_hold': bool(status & STATUS_CAP),     # Auto Cap actif
        'surface': bool(status & STATUS_SURFACE),  # retour surface prioritaire actif
        'watchdog': bool(status & STATUS_WDG),
        'dry_run': bool(status & STATUS_DRYRUN),
        'quat': (w / 10000.0, x / 10000.0, y / 10000.0, z / 10000.0),
        'gyro': (gx / 100.0, gy / 100.0, gz / 100.0),          # °/s
        'pressure_mbar': pressure / 10.0,                       # mbar
        'temperature_c': temperature / 100.0,                   # °C
        'power': list(rest[:6]),                                # mV / mA
        'pwm_us': list(rest[6:22]),                             # µs
        'gpio_state': rest[22],                                 # masque réel des 4 sorties ON/OFF
    }

# ==================== Trame de configuration des noms (27 octets) ====================

def parse_config_frame(frame: bytes) -> dict:
    """Valide et décode une trame de configuration des noms (types 0x03/0x04)."""
    if len(frame) != 27:
        raise ValueError(f'trame de {len(frame)} octets (attendu 27)')
    if frame[0] != 0x55 or frame[1] != 0xAA or frame[2] not in (UL_CFG_PWM, UL_CFG_GPIO):
        raise ValueError('en-tête ou type invalide')
    if (frame[25] << 8 | frame[26]) != crc16_ccitt(frame[2:25]):   # CRC sur [2..24]
        raise ValueError('CRC16 invalide')
    name_len = frame[4]
    if name_len > 20:
        raise ValueError('name_len > 20')
    return {
        'kind': 'pwm' if frame[2] == UL_CFG_PWM else 'gpio',
        'id': frame[3],                                            # canal 10-15 | sortie 1-4
        'name': frame[5:5 + name_len].decode('utf-8', errors='replace'),
        'default_name': name_len == 0,                             # → appliquer votre libellé
    }

class UplinkReader:
    """Réassemble les trames montantes (73 ou 27 octets) dans un flux bruité :
    resynchronisation sur 0x55 0xAA, taille déduite du type (offset 2)."""

    def __init__(self):
        self.buf = bytearray()

    def feed(self, data: bytes):
        """Ajoute des octets reçus ; retourne la liste des trames valides (bytes)."""
        self.buf.extend(data)
        frames = []
        while True:
            idx = self.buf.find(b'\x55\xaa')
            if idx < 0:
                del self.buf[:-1]          # conserve au plus 1 octet (préfixe possible)
                break
            del self.buf[:idx]
            if len(self.buf) < 3:
                break
            size = FRAME_SIZES.get(self.buf[2])
            if size is None:               # type inconnu : faux en-tête probable
                del self.buf[:1]
                continue
            if len(self.buf) < size:
                break
            frame = bytes(self.buf[:size])
            if (frame[size - 2] << 8 | frame[size - 1]) == crc16_ccitt(frame[2:size - 2]):
                frames.append(frame)
                del self.buf[:size]
            else:
                del self.buf[:1]           # CRC invalide : avancer d'un octet
        return frames

# ==================== Boucle principale ====================

def main():
    port = serial.Serial(PORT, BAUD, timeout=0)   # lecture non bloquante
    reader = UplinkReader()
    names = {}                                     # libellés reçus de l'ESP32 (v1.5.0)
    pwm = [1500] * 16                              # toutes voies au neutre
    pwm[0] = 1600                                  # exemple : M1 en avant (µs)
    gpio = 0b0000                                  # sorties ON/OFF (bit 0 = sortie 1)

    port.write(build_sync_request())               # demande les noms (trames 0x03/0x04)

    next_tx = time.monotonic()
    try:
        while True:
            now = time.monotonic()
            if now >= next_tx:                     # --- émission descendante 25 Hz ---
                next_tx += 1.0 / TX_HZ
                port.write(build_downlink_frame(MODE_PASSIF, ARM_ARMED, pwm, gpio))

            for frame in reader.feed(port.read(port.in_waiting or 4096)):
                if frame[2] == UL_TELEMETRY:       # --- télémétrie (73 octets) ---
                    t = parse_uplink_frame(frame)
                    print('quat=(%.3f, %.3f, %.3f, %.3f)  P=%.1f mbar  T=%.1f C  '
                          'pwm0=%d  gpio=0x%X  wdg=%s  dry=%s'
                          % (*t['quat'], t['pressure_mbar'], t['temperature_c'],
                             t['pwm_us'][0], t['gpio_state'], t['watchdog'], t['dry_run']))
                else:                              # --- config noms (27 octets) ---
                    c = parse_config_frame(frame)
                    names[(c['kind'], c['id'])] = c['name'] or f"<défaut {c['kind']}{c['id']}>"
                    print('config :', c['kind'], c['id'], '->', names[(c['kind'], c['id'])])
            time.sleep(0.001)
    finally:
        port.close()

if __name__ == '__main__':
    main()
```

---

## 8. Vecteurs de test (à utiliser pour valider votre parseur)

### 8.1 Valeur de contrôle CRC

```python
assert crc16_ccitt(b'123456789') == 0x29B1
```

### 8.2 Trame descendante de référence

`MODE_PASSIF` + `ARM_ARMED` + toutes voies à 1500 µs + `gpio_cmd = 0x05` (sorties 1 et 3 à ON) :

```
AA 55 01 00 01 DC 05 DC 05 DC 05 DC 05 DC 05 DC 05 DC 05 DC 05
DC 05 DC 05 DC 05 DC 05 DC 05 DC 05 DC 05 DC 05 05 30 72
```

* 40 octets. `DC 05` = `0x05DC` = 1500 LE, répété 16 fois. `gpio_cmd = 0x05` à l'offset 37. CRC final `0x3072` (octet fort `0x30` puis `0x72`).
* Génération : `build_downlink_frame(0, 1, [1500]*16, 0x05).hex() == 'aa55010001' + 'dc05'*16 + '05' + '3072'``

### 8.3 Trame montante de référence

Télémétrie à l'équilibre (quaternion identité, 1013,2 mbar, 25,00 °C), `status = 0x12` (liaison + dry-run), canal 0 à 1600 µs, les autres à 1500, `gpio_state = 0x05` (sorties 1 et 3 à ON) :

```
55 AA 02 12 10 27 00 00 00 00 00 00 00 00 00 00
00 00 94 27 00 00 C4 09 00 00 88 13 20 03 E0 2E
2C 01 D0 39 68 5B 40 06 DC 05 DC 05 DC 05 DC 05
DC 05 DC 05 DC 05 DC 05 DC 05 DC 05 DC 05 DC 05
DC 05 DC 05 DC 05 05 B3 01
```

Décodage attendu :

| Champ | Valeur décodée |
| :--- | :--- |
| `status` | `0x12` → liaison établie + dry-run (`watchdog` = 0) |
| `quat` | `(1.0, 0.0, 0.0, 0.0)` |
| `gyro` | `(0.0, 0.0, 0.0)` °/s |
| `pressure_mbar` | `1013.2` |
| `temperature_c` | `25.0` |
| `power` | `[5000, 800, 12000, 300, 14800, 23400]` → sémantique v1.1.0 (valeurs de test arbitraires) : V_BAT 5,0 V, réservé 800, signal H 12,0 V / courant H 0,3 A, signal V 14,8 V / courant V 23,4 A — voir §5.2 |
| `pwm_us` | `[1600, 1500, 1500, …, 1500]` (16 valeurs) |
| `gpio_state` | `0x05` → sorties 1 et 3 à ON (offset 70) |
| CRC | `0xB301` (offset 71 = `0xB3`, offset 72 = `0x01`) |

### 8.4 Test de robustesse du réassemblage

Injecter du bruit texte, couper une trame en deux, insérer un faux en-tête `55 AA 02 00`, puis vérifier que `UplinkReader.feed()` restitue exactement **2 trames valides**. Le code du §7 (classe `UplinkReader`) est conçu pour ce cas : validé sur la séquence `bruit + moitié1`, puis `moitié2 + faux en-tête + trame complète + bruit`.

Le même test avec une **trame de configuration intercalée** (27 octets) entre deux trames de télémétrie doit restituer **3 trames valides** (2× `0x02` + 1× `0x03`/`0x04`) — c'est le cas réel sur le fil dès qu'une synchronisation est en cours.

### 8.5 Trame de configuration PWM de référence — type `0x03`

Canal **11** nommé « Treuil avant » (`name_len = 0x0C` = 12 octets) :

```
55 AA 03 0B 0C 54 72 65 75 69 6C 20 61 76 61 6E
74 00 00 00 00 00 00 00 00 38 54
```

* 27 octets. `id = 0x0B` = canal 11 ; nom `54 72 65 75 69 6C 20 61 76 61 6E 74` = « Treuil avant », complété de `00` (offsets 17–24) ; CRC `0x3854` sur `[2..24]`.
* Vérification :

```python
assert parse_config_frame(bytes.fromhex(
    '55aa030b0c' + '54726575696c206176616e74' + '00' * 8 + '3854')) \
    == {'kind': 'pwm', 'id': 11, 'name': 'Treuil avant', 'default_name': False}
```

### 8.6 Trame de configuration TOR de référence — nom par défaut

Sortie **2** sans nom personnalisé (`name_len = 0` ⇒ le RPi 5 applique son libellé par défaut) :

```
55 AA 04 02 00 00 00 00 00 00 00 00 00 00 00 00
00 00 00 00 00 00 00 00 00 99 EB
```

* 27 octets. `id = 0x02` = sortie 2 ; `name_len = 0` ; CRC `0x99EB`.
* Vérification :

```python
assert parse_config_frame(bytes.fromhex('55aa0402' + '00' * 21 + '99eb')) \
    == {'kind': 'gpio', 'id': 2, 'name': '', 'default_name': True}
```

### 8.7 Requête de synchronisation de référence — type `0xFF`

Trame descendante minimale (contenu à zéro — ignoré par le firmware) :

```
AA 55 FF 00 00 00 00 00 00 00 00 00 00 00 00 00
00 00 00 00 00 00 00 00 00 00 00 00 00 00 00 00
00 00 00 00 00 00 CA 33
```

* 40 octets. `type = 0xFF` à l'offset 2 ; CRC `0xCA33` sur `[2..37]`.
* Vérification :

```python
assert build_sync_request().hex() == 'aa55ff' + '00' * 35 + 'ca33'
```

---

## 9. Dépannage côté RPi 5

| Symptôme | Cause probable / Remède |
| :--- | :--- |
| `PermissionError` à l'ouverture du port | Utilisateur hors groupe `dialout` : `sudo usermod -aG dialout $USER` puis reconnexion. |
| Aucune trame reçue | 1) Interface choisie côté ESP32 (onglet Paramètres : USB-CDC / UART GPIO) ≠ branchement. 2) Baud ≠ **921600**. 3) UART : TX/RX **croisés** et GND commun. 4) UART Pi non activé (`raspi-config`). |
| Trames reçues mais CRC invalide en permanence | Endianness du CRC inversé (le CRC est **big-endian**, cf. §3.2) ou trame décodée sur un mauvais alignement. |
| Texte `[SERIAL] …` entre les trames binaires | Normal en mode **USB-CDC** (debug partagé) : le `UplinkReader` du §7 filtre tout seul. Pour un lien 100 % propre, passer en **UART matériel**. |
| Trames de **39/72 octets** (au lieu de 40/73) | **Firmware antérieur à la v1.1.0** (sans sorties ON/OFF, voir §10.1) : reflasher le firmware (USB ou OTA). Un parseur conforme au présent document rejettera ces trames (CRC décalé d'un octet). |
| Trames de **71 octets** (au lieu de 73) | **Firmware antérieur au correctif historique de taille montante** (voir §10.2) : reflasher. |
| Interruption de télémétrie de ~2-4 s puis reprise avec `dry=True` | **Normal** : redémarrage automatique du watchdog IMU (BNO085 définitivement muet, §6.5). La propulsion est restée au neutre pendant toute l'opération ; réactiver les sorties depuis l'interface Web si nécessaire. |
| `wdg=True`/`dry=True` persistants dans la télémétrie | `wdg` : vérifier que vos trames partent bien toutes les < 500 ms (et CRC valide). `dry` : activer les sorties via l'interface Web (bouton « Sorties Matérielles »). |
| Propulseurs inertes malgré `arm_state = 1` | Dry-run actif (`dry=True`) ou watchdog déclenché. Vérifier `status` dans la télémétrie. |

---

## 10. Notes de version

### 10.1 v1.1.0 — ajout des sorties tout-ou-rien (39/72 → 40/73 octets)

La version 1.1.0 du protocole ajoute les 4 sorties ON/OFF :

* trame descendante : champ `gpio_cmd` à l'offset **37** ⇒ **40 octets**, CRC sur `[2..37]` stocké en `[38]`/`[39]` ;
* trame montante : champ `gpio_state` à l'offset **70** ⇒ **73 octets**, CRC sur `[2..70]` stocké en `[71]`/`[72]`.

Un firmware antérieur (v1.0.0) émet et attend des trames de **39/72 octets** : l'incompatibilité est **binaire et totale** — les deux extrémités (firmware ESP32 et code RPi 5) doivent être mises à jour ensemble. Le firmware actuel embarque des `static_assert` (vérifiés à la compilation) garantissant tailles et offsets.

### 10.2 Correctif historique — trame montante 71 → 72 octets

Un défaut historique affectait la trame montante : la constante de taille valait **71** alors que la structure `UplinkFrame_t` occupait **72** octets. Conséquences pour les firmwares antérieurs à ce correctif :

* trame émise sur le fil : **71 octets** (dernier octet jamais transmis) ;
* CRC calculé sur `[2..68]` et stocké aux offsets **69–70** (au lieu de 71–72 depuis la v1.1.0, voir §10.1) ;
* l'octet de poids fort du canal `pwm_actual[15]` était **écrasé par le CRC**.

Si vous observez des trames de **71 octets** sur le fil, le firmware en place est antérieur à ce correctif : **reflasher** (USB ou OTA depuis l'interface Web). Le firmware actuel émet la trame **conforme à ce document** (73 octets, CRC sur `[2..70]`).

### 10.3 v1.4.0 — mode combinatoire (masque de bits) et confirmations d'assistance

**Tailles et offsets inchangés** (40/73 octets) : seuls les champs `mode` (offset 3, descendante) et `status` (offset 3, montante) changent de sémantique.

* **Descendante** : `mode` n'est plus une valeur énumérée (0, 1, 2) mais un **masque de bits** — bit 0 (`0x01`) Auto R/T, bit 1 (`0x02`) Tenue de Profondeur, bit 2 (`0x04`) Auto Cap, bit 3 (`0x08`) Retour Surface (prioritaire). Les assistances se **superposent** (ex. `0x03` = Auto R/T + Tenue de Profondeur) ; bits 4–7 ignorés (masqués, sans erreur CRC).
* **Montante** : `status` confirme l'activation **réelle et combinée** des boucles au moment de l'émission — bit 2 (`0x04`) Auto R/T, bit 5 (`0x20`) Tenue de Profondeur, bit 6 (`0x40`) Auto Cap, bit 7 (`0x80`) Retour Surface.
* **Sémantique de capture** : l'activation de la tenue de profondeur capture la **profondeur courante** comme consigne (maintien sur place) ; l'activation de l'Auto Cap capture le **cap courant**. Ces consignes sont recapturées à chaque changement de masque.
* ⚠️ **Incompatibilité sémantique** : un code conçu pour l'ancien protocole qui envoie `mode = 2` (ex-Auto Full) n'active plus que la **tenue de profondeur**. L'équivalent de l'ancien Auto Full est désormais `0x07` (R/T + profondeur + cap).

### 10.4 v1.5.0 — synchronisation des noms (source unique de vérité)

**Tailles des trames principales inchangées** (40 descendante / 73 montante) : la v1.5.0 ajoute des types de trames nouveaux — un parseur existant continue de fonctionner (voir compatibilité ci-dessous).

* **Nouvelle trame descendante `0xFF`** — requête de synchronisation (40 octets, contenu ignoré) : le RPi 5 l'envoie au démarrage pour récupérer les noms personnalisés (§4.4). Elle réarme le watchdog et ne modifie aucune consigne.
* **Nouvelles trames montantes `0x03`** (noms des canaux PWM 10–15, `id` = canal) et **`0x04`** (noms des sorties TOR 1–4, `id` = sortie) — **27 octets chacune**, émises une fois par sortie en **rafale lissée** (une trame par cycle de 10 ms, intercalée entre deux télémétries complètes) sur trois déclencheurs : requête `0xFF`, première commande reçue après (re)connexion, ou modification des noms via l'interface Web (§5.6).
* **Compatibilité ascendante** : un ancien parseur qui filtre `type == 0x02` et la taille 73 ignore naturellement les trames `0x03`/`0x04` (la resynchronisation octet par octet retrouve la télémétrie suivante). Il est toutefois **recommandé** d'étendre le lecteur au dispatch par taille (§3.3 / §7) pour exploiter la synchronisation.
* **Compatibilité descendante** : un ancien firmware (avant v1.5.0) qui reçoit une requête `0xFF` la rejette comme type inconnu (CRC valide requis) — sans effet de bord. Le cockpit peut donc émettre la requête inconditionnellement au démarrage.

---

**Auteur :** DERO DIDIER — [ddero2014@gmail.com](mailto:ddero2014@gmail.com)
*Document garanti conforme au firmware BOB-CONTROL — toute modification du protocole (`include/protocol.h`) doit être répercutée ici.*

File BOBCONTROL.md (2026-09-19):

# BOB-CONTROL - Contrôleur Temps Réel ROV

**Version :** 1.3.0  
**Plateforme :** ESP32-S3 (PlatformIO / Arduino Core / FreeRTOS)  
**Auteur :** Didier Dero  
**Projet associé :** BOB-ROV (Cockpit Raspberry Pi 5)  
**Date :** Septembre 2026  

---

## 🎯 Philosophie & Rôle Système

**BOB-CONTROL** est le micrologiciel temps réel dédié à la gestion basse couche du sous-marin **BOB-ROV**. Embarqué sur un **ESP32-S3**, il isole les fonctions critiques de pilotage matériel et d'acquisition de données du système d'exploitation hôte (Raspberry Pi 5).

Il remplit un quadruple rôle :
1. **Acquisition & Fusion Capteurs :** Lecture haute fréquence des deux bus I2C matériels (centrale inertielle BNO085 **seule** sur le bus n°1 ; triple mesure d'énergie INA3221, wattmètres INA226, pression/profondeur MS5837 et contrôleur PWM PCA9685 sur le bus n°2 — chaque module étant re-routable — bus **et** adresse — via le routage Plug & Play v1.3.0).
2. **Contrôleur de Vol PID :** Stabilisation automatique roulis/tangage/cap/profondeur avec mixage différentiel sur les 8 propulseurs.
3. **Génération PWM Matérielle :** Contrôle autonome de 16 canaux PWM indépendants via PCA9685 (8 propulseurs, servos pan/tilt, pince, gradateurs d'éclairage), avec serveur Web/WebSocket autonome et portail captif pour la configuration et le banc de test.
4. **Gestion de Sécurité Propulsion (v1.1.0) :** check des propulseurs au démarrage (après la connexion Wi-Fi, non bloquant), surveillance surintensité continue via ACS770/INA3221, isolation logicielle du moteur en défaut et remontée d'urgence automatique avec les moteurs verticaux restants.

---

## 🏗️ Architecture Matérielle & Adressage

### 1. Périphériques I2C — Deux Bus Matériels

L'ESP32-S3 possède deux contrôleurs I2C indépendants. La répartition ci-dessous est la **configuration câblée de référence** : l'IMU BNO085 est **seule** sur le bus n°1 (son protocole SH-2 ne tolère aucune cohabitation), tous les autres périphériques vivent sur le bus n°2. Chaque module est re-routable dynamiquement — bus **et** adresse I2C (routage Plug & Play v1.3.0, voir section suivante) :

| Composant | Rôle | Adresse I2C | Bus I2C | Description technique |
| :--- | :--- | :--- | :--- | :--- |
| **BNO085** | IMU 9-DOF | `0x4A` | **n°1 (GPIO 10/11)** | **Seul périphérique du bus n°1** (toute cohabitation perturbe le flux SHTP). Fusion inertielle embarquée (protocole SH-2 via Adafruit BNO08x) : Rotation Vector 9-DOF (cap magnétique) + Game Rotation Vector (secours) + gyroscope calibré @ 50 Hz. Monté tourné de 90° (X capteur vers la droite du ROV) : quaternion **et** gyroscope remappés à la source dans le repère véhicule via `BNO085_MOUNT_YAW_DEG` (−90°) |
| **INA3221** | Énergie Propulsion (v1.1.0) | `0x40` | **n°2 (GPIO 12/13)** | Triple mesure : **Ch1** tension batterie V_BAT (`IN1+`), **Ch2/3** courants des propulseurs via capteurs à effet Hall **ACS770-100U** (sortie `VOUT` 0,5–4,5 V câblée sur `IN-` et lue sur le registre de tension bus — `I (A) = (V_bus_mV − 500) / 40`, plage utile 0–100 A ; voir « Mesure d'Énergie »). Pilote maison (moyennage ×16, ≈35 Hz/canal, identifiant fabricant `0x5449` vérifié au boot) |
| **INA226 #2** | Puissance Aux/LEDs | `0x44` | n°2 (GPIO 12/13) | Wattmètre résiduel éventuel — mesure de ligne d'éclairage et accessoires 12V |
| **INA226 #3** | Puissance Moteurs | `0x45` | n°2 (GPIO 12/13) | Wattmètre résiduel éventuel — mesure de ligne de puissance batterie/propulsion principale |
| **MS5803-30BA / MS5837** | Pression & Profondeur | `0x76` | **n°2 (GPIO 12/13)** | Capteur piézorésistif haute résolution étanche, compensation 24-bit (coefficients C1-C6) |
| **PCA9685** | Contrôleur PWM 16 Ch | `0x41` (ex.) | **n°2 (GPIO 12/13)** | Générateur PWM 12 bits autonome (VCC 3.3V, V+ 5V/Servo). **Re-adressé par straps A0–A5** (0x41 ou 0x42) pour cohabiter avec l'INA3221 qui occupe `0x40` sur le même bus |

> **Note — pourquoi deux bus :** le MS5837-30BA branché sur le même bus que le BNO085 perturbait ses lectures SHTP (tempête de NACK, horizon figé) — et plus généralement, toute cohabitation sur le bus de l'IMU. La règle câblée retenue est donc : **l'IMU seule sur le bus n°1**, tous les autres périphériques sur le bus n°2. Bus n°1 `Wire` (GPIO 10/11, configurables en NVS) et bus n°2 `Wire1` (GPIO 12/13, configurables en NVS). Chaque bus possède ses propres résistances de pull-up (4,7 kΩ vers 3V3). Depuis la v1.3.0, la répartition « quel module vit sur quel bus » **et l'adresse I2C de chaque module** ne sont plus codées en dur : elles sont **routées dynamiquement** (Plug & Play, voir ci-dessous).

**Schéma de câblage des deux bus I2C :**

```
               ┌──────────────────────────┐
               │        ESP32-S3          │
               └──────┬────────────┬──────┘
                      │            │
   ┌──────────────────┴───────┐  ┌─┴────────────────────────────────────────┐
   │ Bus n°1 — « Wire »       │  │ Bus n°2 — « Wire1 »                      │
   │ SDA GPIO 10 / SCL GPIO 11│  │ SDA GPIO 12 / SCL GPIO 13                │
   │ pull-ups 4,7 kΩ → 3V3    │  │ pull-ups 4,7 kΩ → 3V3                    │
   │                          │  │                                          │
   │  └─ BNO085      @ 0x4A   │  │  ├─ INA3221      @ 0x40  — énergie       │
   │     (IMU — SEUL)         │  │  ├─ PCA9685      @ 0x41  — PWM 16 ch.    │
   │                          │  │  ├─ MS5837-30BA  @ 0x76  — profondeur    │
   │                          │  │  └─ INA226 #2/#3 @ 0x44 / 0x45 (résid.)  │
   └──────────────────────────┘  └──────────────────────────────────────────┘
```

### 2. Routage I2C Plug & Play (v1.3.0 — bus ET adresses)

La topologie ci-dessus est la **configuration câblée de référence** du ROV, portée par la carte de routage NVS (appliquée au boot). À la toute première mise sous tension (NVS vierge), le firmware démarre sur sa répartition par défaut **historique** (bus n°1 : BNO085 + INA3221 + 2× INA226 ; bus n°2 : MS5803 + PCA9685, GPIO 6/7) — enregistrer une fois le routage de référence depuis l'interface fige la configuration ci-dessus. Chacun des **six modules routables** (BNO085, INA3221, INA226 #2, INA226 #3, MS5803/MS5837, PCA9685) peut être réassigné — **bus n°1 ou n°2 et adresse I2C** — depuis l'interface Web (onglet Paramètres → carte Scanner → **« Routage I2C Plug & Play »**), au fil d'un flux Plug & Play complet :

1. **Câbler** le module avec ses straps matériels (INA226 A0/A1, BNO085 PS0/PS1, MS5837 CSB…).
2. **Scanner** les deux bus (bouton « Scanner les bus I2C ») — les adresses détectées alimentent immédiatement les sélecteurs d'adresses du routage, sans recharger la page.
3. **Choisir** bus et adresse dans la table — chaque sélecteur d'adresse ne propose que les adresses **réellement découvertes par le scan** sur le bus sélectionné ; l'adresse routée actuelle reste visible en « (actuelle) » si le module n'est pas détecté.
4. **Enregistrer** → le routage est écrit en NVS et appliqué au **redémarrage différé de 3 s** (application au boot uniquement, jamais à chaud — voir API REST ci-dessous).

Aucune adresse n'est codée en dur dans les chemins de code : les constantes de `config.h` ne servent que de **défauts NVS** au premier démarrage, et toutes les transactions du firmware passent par `g_i2cRouter.addrOf()` / `busOf()` — capteurs (sondes de boot, lectures, re-sonde périodique, récupération de bus) comme PCA9685 (alloué par `PWMController::begin()` sur son adresse routée).

* **Persistance :** namespace NVS « config », **douze clés** — six bus `route_bno085`, `route_ina3221`, `route_ina226_2`, `route_ina226_3`, `route_ms5803`, `route_pca9685` (valeur 1 = `Wire`, 2 = `Wire1`) et six adresses `addr_bno085`, `addr_ina3221`, `addr_ina226_2`, `addr_ina226_3`, `addr_ms5803`, `addr_pca9685` (0x01–0x7F) — effaçables avec les autres paramètres via « Réinitialiser les paramètres ». La carte est chargée par `SensorDriver::begin()` **avant toute sonde de présence** ; chaque composant reçoit ensuite le pointeur `TwoWire` de SON bus (`&Wire` ou `&Wire1`) et **son adresse routée**.
* **API REST :** `GET /api/i2c/routing` (carte courante : modules + adresses hex/décimales + bus, broches des deux bus, bus protégé PWM, état de conflit, **dernier scan I2C intégré** au format de `/api/i2c/scan`) ; `POST /api/i2c/routing` (les **DOUZE clés** requises — paires `module`/`module_addr` — bus 1 ou 2, adresse décimale (`74`) ou hexadécimale (`0x4A`) — form-urlencoded ou JSON). Écriture NVS **vérifiée par relecture**, puis **redémarrage différé de 3 s** : le routage ne s'applique **qu'au boot**, jamais à chaud — même discipline que les broches SDA/SCL.
* **Conflit d'adresse généralisé :** deux modules routés sur le **même bus à la même adresse** est refusé — pas seulement le cas historique INA3221 ↔ PCA9685 (tous deux `0x40`) : la sauvegarde est **refusée** (HTTP 400, les deux modules en conflit nommés dans l'erreur) côté firmware, et l'interface bloque le bouton (avertissement live sur toute paire `bus:adresse` dupliquée).
* **Règle de sûreté du bus PWM :** le bus hébergeant le PCA9685 (`pwmBus()`) n'est **jamais bit-bangé ni reseté en vol** : le watchdog I2C global et la récupération de bus du scanner ne réinitialisent que **l'autre bus**. Les capteurs routés sur le bus PWM restent réinitialisables (réécriture de leurs registres) mais leur bus n'est pas réparable à chaud — limitation documentée : en cas d'effondrement du bus PWM, seul un redémarrage le répare.
* **Verrou Check Propulseurs :** le verrou `_inaBusLock` suit le bus **routé** de l'INA3221 (sérialisation entre la tâche `Motors` et la tâche capteurs sur ce bus).

### 3. Liaison Série RPi 5 — Deux Modes Configurables

Le protocole binaire RPi 5 ↔ ESP32-S3 peut emprunter **deux interfaces physiques** au choix, sélectionnable via l'onglet Paramètres de l'interface Web et persisté en NVS :

| Mode | Interface | Broches / Port | Côté RPi 5 | Description |
| :--- | :--- | :--- | :--- | :--- |
| **USB-CDC Natif** | `Serial` (USB) | Port USB-C de l'ESP32-S3 | `/dev/ttyACM0` | Protocole binaire sur le port USB natif. Le debug moniteur partage le même port. |
| **UART Matériel** | `Serial1` (UART1) | RX: **GPIO 1**, TX: **GPIO 2** | UART GPIO (921 600 bauds) | Protocole binaire dédié sur UART matériel. USB-CDC reste exclusivement réservé au debug. |

> **Note :** Par défaut, le mode **USB-CDC** est actif. Le choix est mémorisé en NVS (clé `comm_iface`) et rechargé à chaque démarrage. Un **redémarrage** est nécessaire après changement via l'interface Web.

#### Broches UART (mode UART matériel uniquement)

| Signal | GPIO | Direction | Description |
| :--- | :--- | :--- | :--- |
| **UART1 RX** | GPIO 1 | ESP32 ← RPi 5 | Réception trame descendante |
| **UART1 TX** | GPIO 2 | ESP32 → RPi 5 | Émission trame montante |

### 4. Affectation des Canaux PWM (PCA9685)

* **Canaux 0 à 7 :** 8 × ESC Propulseurs ($1000\,\mu\text{s}$ à $2000\,\mu\text{s}$, neutre à $1500\,\mu\text{s}$)
* **Canaux 8 & 9 :** Servomoteurs Pan & Tilt Caméra ($50\text{ Hz}$)
* **Canaux 10 & 11 :** Outil / Pince & Rotation — **Bidirectionnel** par défaut (neutre $1500\,\mu\text{s}$)
* **Canaux 12 & 13 :** Gradateurs MOSFET pour projecteurs LED — **Unidirectionnel** par défaut ($1000\,\mu\text{s} = 0\,\% \rightarrow 2000\,\mu\text{s} = 100\,\%$)
* **Canaux 14 & 15 :** Canaux auxiliaires / Extensions — **Bidirectionnel** par défaut

> **Typage configurable (canaux 10 à 15) :** chaque canal 10–15 est typable individuellement en **Bidirectionnel** (neutre $1500\,\mu\text{s}$, plage $1000-2000\,\mu\text{s}$) ou **Unidirectionnel / pleine échelle** ($1000\,\mu\text{s} = 0\,\%$, $2000\,\mu\text{s} = 100\,\%$) depuis l'onglet Paramètres — persistance NVS (clé `pwm_types` : masque 6 bits, bit n ↔ canal 10+n, 1 = bidirectionnel ; défaut `0x33`), appliqué **à chaud** sans redémarrage. Le typage ne modifie pas la plage des consignes (toujours bornées à 1000–2000 µs) : il détermine la **position de sécurité** appliquée par le failsafe (1500 µs en bidirectionnel, 1000 µs en unidirectionnel) et le rendu dynamique des barregraphes du **PWM Monitor**.

### 5. Sorties Tout-ou-Rien — 4 × GPIO ON/OFF

Quatre sorties numériques auxiliaires pilotées directement par l'ESP32-S3 (relais, éclairage tout-ou-rien, accessoires) :

| Sortie | GPIO par défaut | Commande (bit de `gpio_cmd`) | État (bit de `gpio_state`) |
| :--- | :--- | :--- | :--- |
| 1 | GPIO 15 | bit 0 | bit 0 |
| 2 | GPIO 16 | bit 1 | bit 1 |
| 3 | GPIO 17 | bit 2 | bit 2 |
| 4 | GPIO 18 | bit 3 | bit 3 |

* **Assignation configurable :** les numéros de GPIO sont modifiables dans l'onglet Paramètres et persistés en NVS (clés `gpio_p1`..`gpio_p4`) ; ils ne sont appliqués qu'**au redémarrage** (comme les broches I2C). Validation : broches 0–48 hors GPIO 19/20 (USB), hors broches I2C actives (deux bus) et UART1, sans doublon.
* **Initialisation :** au démarrage, les 4 broches sont configurées en sortie à l'état **BAS (OFF)** ; elles restent pilotables **même désarmé** (sorties auxiliaires).
* **Sécurité :** le déclenchement du watchdog série (perte du flux RPi 5) et l'**E-Stop** forcent les 4 sorties à **OFF** — l'état réel est relu physiquement et remonté dans `gpio_state`.

---

## 📡 Protocole Série Binaire RPi 5 ↔ ESP32-S3

La communication s'effectue à **921 600 bauds** sur l'interface sélectionnée (USB-CDC natif ou UART matériel GPIO 1/2). Toutes les trames sont à taille fixe avec validation par somme de contrôle CRC16-CCITT.

### 1. Trame Descendante : RPi 5 → ESP32-S3 (40 octets @ 20-50 Hz)

```
[0xAA][0x55][TYPE][MODE][ARM_STATE][PWM_0 ... PWM_15][GPIO_CMD][CRC16_HIGH][CRC16_LOW]
```

* **Header :** `0xAA`, `0x55` (2 octets)
* **Type :** `0x01` (1 octet)
* **Mode :** `uint8_t` (`0` = Passif, `1` = AUTO Roulis et Tangage, `2` = Auto-Full)
* **Arm State :** `uint8_t` (`0` = Disarmed, `1` = Armed, `2` = Emergency Stop)
* **PWM Channels (0–15) :** `uint16_t[16]` (32 octets, offsets 5–36, consigne en $\mu\text{s}$)
* **GPIO Command :** `uint8_t` (offset 37, masque 4 bits des sorties ON/OFF — bit 0 = sortie 1 … bit 3 = sortie 4, `1` = ON, `0` = OFF ; bits 4–7 ignorés)
* **CRC16 :** `uint16_t` (2 octets aux offsets [38] fort / [39] faible, polynôme 0x1021, init 0xFFFF — **stocké gros-boutiste** : octet fort puis faible, calculé sur les octets `[2..37]`)

### 2. Trame Montante : ESP32-S3 → RPi 5 (73 octets @ 100 Hz)

```
[0x55][0xAA][TYPE][STATUS][QUAT_W,X,Y,Z][GYRO_X,Y,Z][PRESS,TEMP][INA_1,2,3][PWM_ACT_0...15][GPIO_STATE][CRC16]
```

* **Header :** `0x55`, `0xAA` (2 octets)
* **Type :** `0x02` (1 octet)
* **Status Flags :** `uint8_t` (Bit 0: réservé, Bit 1: Liaison établie — au moins une trame valide reçue depuis le boot, Bit 2: Autopilote actif — réservé, jamais émis, Bit 3: Watchdog déclenché, Bit 4: Sorties physiques neutralisées / Dry-Run)
* **Quaternions IMU :** `int16_t[4]` (8 octets, $W, X, Y, Z$ scalés $\times 10\,000$, repère véhicule — montage BNO085 remappé à la source)
* **Gyroscope :** `int16_t[3]` (6 octets, $\omega_x, \omega_y, \omega_z$ scalés $\times 100$, repère véhicule)
* **Pression & Température :** `int32_t[2]` (8 octets, $0.1\text{ mbar}$ et $0.01\,^\circ\text{C}$)
* **Télémétrie Puissance :** `uint16_t[6]` (12 octets — **format binaire inchangé, sémantique v1.1.0** : $[V_{BAT}\ mV,\ 0,\ V_{signal}\ mV,\ I_H\ mA,\ V_{signal}\ mV,\ I_V\ mA]$ issus de l'INA3221/ACS770 ; anciennement $V$ et $I$ des trois INA226 en $mV$/$mA$)
* **PWM Effectifs :** `uint16_t[16]` (32 octets, offsets 38–69, impulsions réelles envoyées aux actionneurs)
* **GPIO State :** `uint8_t` (offset 70, état **réel relu** des 4 sorties ON/OFF — bit 0 = sortie 1 … bit 3 = sortie 4, `1` = ON)
* **CRC16 :** `uint16_t` (2 octets aux offsets [71] fort / [72] faible, **gros-boutiste**, calculé sur les octets `[2..70]`)

### 3. Watchdog Failsafe

Un watchdog logiciel surveille la réception de trames descendantes. Si aucune trame valide n'est reçue pendant le **timeout configurable** (défaut : 500 ms), chaque canal PWM est automatiquement forcé à sa **position de sécurité** ($1500\,\mu\text{s}$ en bidirectionnel — défaut canaux 0–11, 14–15 ; $1000\,\mu\text{s}$ / $0\,\%$ en unidirectionnel — défaut canaux 12–13, voir « Typage configurable ») et les **4 sorties ON/OFF sont forcées à OFF**.

> **📄 Documentation détaillée pour le développement côté RPi 5 :** voir [PROTOCOLE_RPI5.md](PROTOCOLE_RPI5.md) — description octet par octet des deux trames et des masques de sorties ON/OFF (`gpio_cmd` / `gpio_state`), sémantique exacte des bits de statut, comportements watchdog / armement / maître / dry-run, exemple Python prêt à l'emploi et vecteurs de test.

#### Watchdog IMU — Récupération BNO085 en 3 niveaux

Indépendamment du watchdog série, un **watchdog dédié surveille le flux de quaternions du BNO085** (Rotation Vector ou Game Rotation Vector — le gyroscope ne compte pas). Constat opérationnel : en plongée ou après une longue période d'inactivité, la communication avec le capteur (seul sur le bus I2C n°1) peut se figer définitivement. Si aucun quaternion n'est reçu pendant **1 s** (`BNO085_STALL_TIMEOUT_MS`), la récupération escalade automatiquement :

| Niveau | Déclenchement | Action | Propulsion |
| :--- | :--- | :--- | :--- |
| **1 — Reprise douce SH-2** | 1er échec (stall 1 s sans quaternion) | Ré-initialisation logicielle du capteur (réécriture des rapports SH-2) | **Forcée au neutre** pendant la récupération |
| **2 — Reset matériel du bus I2C** | Échec du niveau 1, ou blocage persistant du contrôleur I2C (`ESP_ERR_INVALID_STATE`) | Destruction de l'instance `Adafruit_BNO08x`, `Wire.end()`, **9 impulsions SCL + condition STOP** (bit-bang), réinitialisation complète de `Wire` (400 kHz, timeout 50 ms), puis recréation de l'instance et réinit de tous les capteurs | **Forcée au neutre** |
| **3 — Ultime secours : redémarrage contrôlé** | **3 tentatives de niveau 2** restées sans effet (`BNO085_REBOOT_ATTEMPTS`) **ou 8 s** sans aucun quaternion (`BNO085_REBOOT_TIMEOUT_MS`) | 1) tous les canaux PWM à leur position de sécurité (neutre $1500\,\mu\text{s}$, ou $1000\,\mu\text{s}$ / $0\,\%$ pour les canaux unidirectionnels), 2) log explicite sur le moniteur série, 3) `esp_restart()` — redémarrage automatique de l'ESP32 | **Position de sécurité physiquement maintenue** pendant tout le reboot (voir ci-dessous) |

**Garantie de maintien au neutre pendant la récupération / le reboot :**

1. **Pendant les niveaux 1 et 2** — la tâche de contrôle (100 Hz) verrouille les canaux 0-7 (propulseurs) à $1500\,\mu\text{s}$ **à chaque cycle** tant que le flux de quaternions est mort (`isBNO085Stalled()`) : une consigne RPi 5 réappliquée entre deux tentatives ne peut jamais repartir avec une attitude inconnue. Les servos/auxiliaires (8-15) ne sont pas concernés.
2. **Au niveau 3** — la neutralisation est doublée d'une écriture physique inconditionnelle sur les 16 canaux (même en Dry-Run) : le **PCA9685 est un générateur autonome qui conserve ses registres pendant le redémarrage de l'ESP32** — les propulseurs restent au neutre tout le reboot ; au redémarrage, le firmware repart en mode Dry-Run et réapplique le neutre.

> **Garde-fou anti-boucle :** le niveau 3 ne se déclenche que si le capteur **a déjà fonctionné depuis le boot** (au moins un quaternion reçu). Un capteur jamais fonctionnel dès la mise sous tension n'est pas redémarré en boucle : il reste en **mode espacé** (polling SHTP coupé, badge rouge + message Web, une tentative complète toutes les 30 s). Ce comportement garantit la récupération automatique du cas opérationnel réel (capteur qui gèle en plongée) sans risquer une boucle de redémarrages sur un capteur défaillant au boot.

---

## 🌐 Interface Web Embarquée & Portail Captif

L'ESP32-S3 héberge une application Web autonome stockée dans la mémoire flash **LittleFS**. Le design suit la charte graphique **BOB CNC** (thème sombre, polices Michroma + Source Code Pro, accents cyan/magenta).

### Portail Captif Automatique

Le point d'accès Wi-Fi (`BOB-CONTROL_AP`, mot de passe : `bobrov2026`) inclut un serveur DNS captif qui redirige **toutes** les requêtes DNS vers `192.168.4.1`. Des handlers HTTP spécifiques interceptent les URLs de détection de portail captif pour chaque OS :

| OS | URL de détection interceptée |
| :--- | :--- |
| Android / ChromeOS | `/generate_204`, `/gen_204`, `/hotspot-detect.html` |
| iOS / macOS | `/library/test/success.html` |
| Windows | `/connecttest.txt`, `/redirect` |
| Firefox | `/canonical.html` |
| Kindle / Fire OS | `/kindle-wifi/wifistub.html` |

La page s'ouvre automatiquement dès la connexion au réseau Wi-Fi.

### Tableau de Bord — Navigation par Tuiles Réorganisables

L'interface principale est un **tableau de bord** composé de tuiles cliquables disposées en grille 2×N. Chaque tuile représente une fonction du système. L'utilisateur peut :

1. **Cliquer sur une tuile** → affiche la section correspondante en pleine page avec un bouton retour (↩).
2. **Cliquer « Réorganiser »** ou **appui long (500 ms) sur une tuile** → active le mode édition : toutes les tuiles se mettent à trembler (jiggle iOS ±1,5°, **désynchronisé par tuile** via data-tile-id), et la tuile sous le doigt se **soulève immédiatement** — elle suit le doigt sans attendre un nouvel appui.
3. **Glisser-déposer les tuiles** → réordonne en temps réel, la tuile survolée fait place dynamiquement (Pointer Events unifiés souris/tactile, **repli touchstart/touchmove/touchend** pour les navigateurs anciens ; jamais l’attribut `draggable` HTML5, inopérant sur iOS Safari). La position est **sauvegardée dans `localStorage` à chaque dépôt** (ordre propre à l’appareil).
4. **Cliquer « Terminer »** ou **taper en dehors des tuiles** → quitte le mode édition.

### Fonctions du Tableau de Bord (6 Sections)

| Tuile | Contenu |
| :--- | :--- |
| **Wi-Fi** | **Connexion actuelle** temps réel : SSID, adresse IP, passerelle (DHCP), masque, RSSI, MAC. Infos point d'accès local (SSID, IP, clients). Scan des réseaux environnants. Connexion STA non-bloquante (sans tuer le point d'accès). |
| **PWM Monitor** | 16 barregraphes temps réel (WebSocket). 8 jauges moteurs bidirectionnelles centrées à $1500\,\mu\text{s}$, servos, gradateurs, auxiliaires. **Rendu dynamique des canaux 10–15 selon leur typage** : Bidirectionnel → curseur centré sur le neutre ($1500\,\mu\text{s}$) ; Unidirectionnel → jauge pleine échelle $0 - 100\,\%$ avec dégradé de couleur progressif vert → orange → rouge. **Commutateur Sorties Matérielles** (Mode Témoin / Dry-Run) : badge d'avertissement ambre/vert. |
| **Télémétrie** | **Cadre ROV 3D** : modèle 3D du ROV (`bob_rov_3D.glb`, LittleFS `/3D/`) animé en temps réel par l'IMU (roulis/tangage/cap) — three.js r128 servi **localement** (`/vendor/three.min.js`, aucun CDN : le ROV diffuse son AP sans Internet) et parseur GLB minimal embarqué (couleurs plates, sans texture) ; orbite/zoom à la souris, double-clic = vue initiale, grille polaire et flèche du Nord en référence de cap, cases « Filaire » / « Vert » (wireframe, lignes teintées vert) ; réalignement du modèle à 90° (R3D_MODEL_YAW_DEG) car l’avant exporté d’Onshape ne suit pas la convention glTF (-Z). **Cap magnétique BNO085** : le Rotation Vector 9-DOF (gyro + accéléro + magnétomètre) est la source principale du cap — cap absolu, le Game Rotation Vector relatif restant en secours automatique si le flux s'interrompt ; état de la boussole affiché en continu (source + calibration 0–3, auto-calibration en déplaçant le ROV en « 8 »). **Bouton « Régler Nord »** : tare du cap appliquée à la source — télémétrie, HSI, modèle 3D et PID de cap partagent le même référentiel ; ajustage fin de l'écart résiduel en cap magnétique (une fois suffit), référence obligatoire après chaque boot en secours relatif ; à faire en mode PASSIF. Assiette Euler (Roll/Pitch/Yaw), profondeur, pression, température. **Widget INA3221** (v1.1.0 : tension batterie + courants horizontaux/verticaux en A) et 2 wattmètres INA226. **Statut Moteurs** (v1.1.0) : voyant vert/orange/rouge + détail temps réel (check en cours/échoué, moteurs isolés, remontée d'urgence active). **Sélecteur de Mode de Pilotage** : 3 boutons radio (PASSIF / AUTO ROULIS ET TANGAGE / AUTO FULL) avec badge Maître (RPi 5 vert / Manuel ESP32 orange). Instruments aviation : horizon artificiel et HSI (Heading Situation Indicator) avec lissage LERP. Diagnostic capteurs (LED BNO085, MS5803, INA3221, INA226 ×2, PCA9685). |
| **Banc de Test** | 16 curseurs de commande manuelle **adaptés au typage configuré** (µs 1000–2000 en bidirectionnel ; **0–100 %** avec conversion automatique en µs en unidirectionnel) + **4 sorties GPIO ON/OFF**, avec verrou de sécurité matériel. Chaque sortie affiche son **nom personnalisé** (Paramètres → NVS). Bouton « Tout en position de sécurité » appliquant **par canal** le neutre adapté (1500 µs / 0 %). |
| **Paramètres** | Sélection liaison série RPi 5 (USB-CDC / UART GPIO 1/2). **Configuration Bus I2C n°1 / n°2** : broches SDA/SCL avec sauvegarde NVS et redémarrage automatique du contrôleur après 3 s — même comportement pour les deux bus (broches appliquées au boot ; le bus n°2 est partagé avec les sorties PWM). **Scanner I2C** : scan des deux bus (0x01–0x7F, colonne Bus avec les GPIO réels de chaque bus) avec identification des périphériques — l'étiquette de chaque adresse est arbitrée par le routage bus + adresse des six modules (heuristiques pour les périphériques non routés). **Routage I2C Plug & Play (v1.3.0 — bus et adresses)** : table des six modules avec sélecteur de bus (I2C_0/I2C_1, GPIO réels dans les libellés) et **sélecteur d'adresse** peuplé par les adresses découvertes au dernier scan I2C (filtrées par bus ; l'adresse routée actuelle reste proposée en « (actuelle) »), avertissement live et blocage du bouton sur toute paire bus:adresse en conflit, bouton « Enregistrer le routage I2C » (diff bus ET adresse affiché dans la confirmation) → NVS + redémarrage automatique après 3 s, l'interface ne se rechargeant qu'une fois l'API sert la nouvelle carte (preuve du redémarrage effectif, comme pour les broches). **Typage des canaux PWM 10–15** : 6 sélecteurs Bidirectionnel / Unidirectionnel, appliqués à chaud et persistés en NVS. **Sorties tout-ou-rien** : assignation des 4 GPIO ON/OFF (GPIO 15/16/17/18 par défaut) avec validation (doublons et broches réservées refusés — USB, I2C actifs, UART1), persistance NVS et redémarrage automatique après 3 s ; badges d'état ON/OFF en temps réel et **boutons de test individuels** (forçage direct via `POST /api/gpio/test`, écrasé par le watchdog, l'E-Stop ou une trame RPi 5 maître). **Mise à jour OTA** : téléversement sans câble du micrologiciel (firmware.bin) ou des fichiers Web (littlefs.bin) avec progression, neutralisation de la propulsion et redémarrage automatique. PID (Roll, Pitch, Yaw, Profondeur) : Kp, Ki, Kd. Timeout watchdog série réglable. **Calibration Altimètre (QNH)** : interrupteur d'activation (persisté NVS) et bouton « Actualiser le QNH maintenant » avec spinner (Open-Meteo — Chamoson, VS) — ne corrige que l'altitude barométrique hors de l'eau (voir Notes Techniques). **Gestion Moteurs — Sécurité Propulsion (v1.1.0)** : 5 paramètres NVS (check au démarrage, détection surintensité & isolation, remontée d'urgence, seuil d'intensité max, seuil de tension batterie) + bouton de relance manuelle du check (voir section dédiée). |
| **Câblage** | Schéma visuel ESP32-S3 (`esp32s3.png`). Liaison RPi 5 dynamique selon le mode actif (USB-CDC ou UART GPIO 1/2) avec diagrammes ASCII et tables de correspondance. Tableaux complets des deux bus I2C : broches SDA/SCL (bus n°1 GPIO 10/11, bus n°2 GPIO 12/13), adresses et fonctions de chaque module (IMU, wattmètres, baromètre, PCA9685). **Depuis la v1.3.0, toute la page suit le routage Plug & Play actif** : titres, schémas ASCII, tableaux de brochage, **adresses I2C affichées** et badges « Bus I2C » de chaque module sont reconstruits à partir de la carte de routage réellement chargée (repli sur la topologie par défaut tant que l'API n'a pas répondu ; un bus entièrement vidé affiche un message à la place du schéma). |

### Connexion Wi-Fi Externe (Mode STA)

Le firmware fonctionne en mode **WIFI_AP_STA** (point d'accès + station simultanés). La connexion à un réseau Wi-Fi externe utilise `WiFi.begin()` **sans** `WiFi.disconnect()` pour ne pas interrompre le point d'accès. Un callback d'événements Wi-Fi (`ARDUINO_EVENT_WIFI_STA_GOT_IP`) suit l'état de connexion de manière asynchrone.

---

## 🔋 Énergie Propulsion & Sécurité Moteurs (v1.1.0)

L'**INA3221** (triple mesure, bus n°2, `0x40` — pilote maison, aucune bibliothèque) remplace le premier INA226 et supervise l'énergie de propulsion. Les courants sont fournis par deux capteurs à effet Hall **ACS770-100U** (sensibilité 40 mV/A, sortie analogique **0,5 V à 0 A → 4,5 V à 100 A**) dont la broche `VOUT` est câblée sur l'entrée **`IN-`** des canaux 2 et 3 : l'INA3221 y lit cette tension **absolue** sur son **registre de tension bus** (LSB 8 mV, plage 26 V — le registre shunt, plafonné à ±163,84 mV, saturait la mesure à ±4,09 A) et le firmware applique **`I (A) = (V_bus_mV − 500) / 40`**.

| Canal INA3221 | Mesure | Source | Plage utile |
| :--- | :--- | :--- | :--- |
| **1** | Tension batterie propulsion (V_BAT) | `IN1+` (registre bus, LSB 8 mV) | 0–26 V |
| **2** | Courant propulseurs horizontaux M1–M4 | `VOUT` ACS770-H → `IN2-` (registre bus, LSB 8 mV) | 0–100 A |
| **3** | Courant propulseurs verticaux M5–M8 | `VOUT` ACS770-V → `IN3-` (registre bus, LSB 8 mV) | 0–100 A |

Moyennage matériel ×16 (≈35 Hz/canal). Les deux INA226 résiduels (#2 Aux/LED `0x44`, #3 Propulsion `0x45`) restent inchangés.

### Mesure d'Énergie (Propulsion & Batterie) — Câblage INA3221 + ACS770-100U

**Schéma de câblage (tension batterie + courants propulsion) :**

```
   ┌──────────────────────────────────────────────────────────────────────────┐
   │   MESURE D'ÉNERGIE (Propulsion & Batterie) — INA3221 @ 0x40, bus I2C n°2 │
   └──────────────────────────────────────────────────────────────────────────┘

   CANAL 1 — Tension batterie propulsion
     BATTERIE 12 V ───── V_BAT (0–26 V) ────────►  IN1+   (canal 1)
     GND (référence) ───────────────────────────►  IN1-

   CANAL 2 — Courant propulseurs horizontaux (M1–M4)
                   ┌──────────────────┐
     ALIM +12 V ──►│ IP+              │
                   │    ACS770-100U   ├───► IP- ────►  ESC M1–M4
                   │   (courant       │
                   │    traversant)   │
                   │          VOUT ───┼── 0,5–4,5 V ────►  IN2-   (canal 2)
                   └──────────────────┘

   CANAL 3 — Courant propulseurs verticaux (M5–M8)
                   ┌──────────────────┐
     ALIM +12 V ──►│ IP+              │
                   │    ACS770-100U   ├───► IP- ────►  ESC M5–M8
                   │   (courant       │
                   │    traversant)   │
                   │          VOUT ───┼── 0,5–4,5 V ────►  IN3-   (canal 3)
                   └──────────────────┘
```

> * **Le signal analogique des ACS770 (0,5 V à 4,5 V) est lu sur les broches `IN-` des canaux 2 et 3** de l'INA3221 : sortie `VOUT` câblée directement, référencée à la masse commune par les broches opposées (`IN2+`/`IN3+`). Le firmware exploite le **registre de tension bus** (LSB 8 mV, plage 26 V — le registre shunt, plafonné à ±163,84 mV soit ±4,09 A, est inadapté à ce signal) et applique `I (A) = (V_bus_mV − 500) / 40`.
> * **Canal 1 :** `IN1+` est connectée à la tension globale de la batterie (V_BAT) — mesure directe de la tension de propulsion (0–26 V).
> * **Conducteur de puissance :** le courant réellement consommé par chaque banc de propulseurs (M1–M4 horizontaux, M5–M8 verticaux) traverse le capteur (`IP+` → `IP-`, en série sur la ligne d'alimentation des ESC) ; `VOUT` le restitue en tension à 40 mV/A.

**Télémétrie :** WebSocket `power[5]` — canaux 0–2 = INA3221 (`{v, i}` en mV/mA : V_BAT, courant H, courant V), canaux 3–4 = INA226 #2/#3 — plus objet `motors` (`health`, `status`, `check_done`, `check_passed`, `check_pending`, `fault`, `emergency`, `isolated_mask`). **La trame série montante RPi 5 (73 octets) garde son format binaire inchangé** (voir section Protocole).

### Paramètres (onglet Paramètres → « Gestion Moteurs », NVS namespace `motors`)

| Paramètre | Clé NVS | Défaut | Bornes |
| :--- | :--- | :--- | :--- |
| Check Propulseurs au démarrage | `check_enable` | activé | — |
| Détection surintensité & isolation | `detect_enable` | activé | — |
| Remontée d'urgence si moteur vertical isolé | `emergency_enable` | **désactivée** (sûreté) | modifiable seulement si la détection est active |
| Seuil d'intensité max — moteur bloqué | `cur_thresh` | 3,0 A | 0,5–80 A |
| Seuil de tension basse — batterie propulseurs | `vbat_low` | 14,0 V | 9–30 V |

Écriture NVS **vérifiée par relecture** (HTTP 500 en cas d'échec, convention du projet). API REST : `GET/POST /api/motors/config` (corps form-urlencoded — champs absents = valeurs courantes conservées ; le GET renvoie aussi l'état courant du gestionnaire et les bornes), `POST /api/motors/check` (relance manuelle, **409** si séquence en cours ou défaut actif).

### Check des propulseurs au démarrage (non bloquant)

Exécuté par la tâche `Motors` (Core 1, priorité 3 — sous le contrôle/PID, période 100 ms). L'armement du check automatique est **figé au boot** : activer l'option à chaud depuis l'interface ne déclenche **jamais** d'impulsions en navigation — seule la relance manuelle (bouton Paramètres) teste à chaud. La connexion Wi-Fi est attendue **sans blocage** (polling de l'état STA, jamais de boucle d'attente), plus 3 s de stabilisation (`MOTOR_CHECK_POST_WIFI_DELAY_MS`) :

1. **Voyant remis à UNKNOWN**, puis vérification de V_BAT (canal 1) ≥ seuil bas — sinon WARNING (orange) et abandon.
2. **Impulsion séquentielle M1 → M8** : 1600 µs (≈20 % de poussée) par moteur — fenêtre de mesure de 400 ms (stabilisation 150 ms + maximum de 3 lectures espacées de 100 ms, la moyenne ×16 interne de l'INA3221 lissant déjà), retour immédiat au neutre **avant** toute décision, pause de 250 ms entre moteurs ; les canaux déjà isolés ce boot sont ignorés.
3. Courant > seuil pendant l'impulsion → moteur déclaré bloqué et **isolé immédiatement** ; lecture impossible (INA3221 absent/bus occupé) → WARNING et interruption (aucune conclusion sans donnée).
4. **Verdict** : FAULT (rouge) si le moindre isolement subsiste, OK (vert) sinon. Un défaut surintensité détecté pendant l'attente Wi-Fi (ESC en court-circuit) annule le check (échec) — jamais d'état « en attente » éternel dans l'interface.

### Surveillance en navigation, identification et isolation

Si `detect_enable` est actif, la tâche `Motors` surveille les canaux 2/3 à 10 Hz. Le seuil doit être confirmé **3 lectures consécutives** (~300 ms — `MOTOR_OVERCURRENT_CONFIRM`) avant action : immunité aux transitoires d'inversion de poussée, tout en restant bien plus rapide qu'un échauffement destructif. Un canal entièrement isolé (4 moteurs) n'est plus surveillé ; une remontée d'urgence active n'interprète pas le courant vertical (il reflète la poussée de survie).

**Identification du moteur fautif :** isolements **provisoires** successifs, triés par écart |consigne − 1500 µs| décroissant (le moteur le plus sollicité est suspecté en premier). Après chaque isolement (stabilisation 150 ms), le courant est relu : celui dont l'isolement fait retomber le courant sous le seuil est le coupable — les innocents sont **relâchés** (isolement levé, moteur au neutre). Si aucun isolement ne suffit, le canal entier est isolé.

**Isolation logicielle :** tout canal isolé **refuse toute consigne** (RPi 5, PID, banc de test — filtre dans `PWMController::setPWMuS`/`setAllPWM`) et l'isolement écrit **physiquement** le neutre, même en Dry-Run. Seuls un redémarrage ou l'identification d'un innocent lèvent un isolement.

### Remontée d'urgence

Si `emergency_enable` est actif et qu'un moteur **vertical** (M5–M8) vient d'être isolé, le flag de survie s'arme : les moteurs verticaux restants reçoivent **1700 µs** (≈40 % de poussée vers la surface — assez pour remonter avec 3 verticaux sur 4) **en remplacement de toute consigne**. Le filtre est centralisé dans `PWMController` (appliqué à la fréquence d'écriture, 100 Hz) : aucun combat entre une réaffirmation 10 Hz et le PID. Le failsafe série (perte du flux RPi 5) **n'interrompt pas** une remontée — la consigne de survie traverse le neutre logique ; seules des décisions humaines la coupent : **E-Stop** RPi 5 (trame descendante) et **OTA** appellent `abortEmergencySurface()` avant de neutraliser.

Le voyant « Statut Moteurs » (onglet Télémétrie) ne **reverdit jamais seul** (gravité croissante uniquement) : un check manuel relancé le remet à UNKNOWN puis le verdict le repositionne — pratique après correction d'un WARNING batterie.

---

## ⚙️ Configuration PlatformIO

```ini
[env:esp32-s3-devkitc-1]
platform = espressif32
board = esp32-s3-devkitc-1
framework = arduino
monitor_speed = 115200
board_build.partitions = bob_control_8mb.csv
board_build.filesystem = littlefs
build_flags = 
    -D ARDUINO_USB_MODE=1
    -D ARDUINO_USB_CDC_ON_BOOT=1

lib_deps = 
    mathieucarbou/ESPAsyncWebServer @ ^3.6.0
    mathieucarbou/AsyncTCP @ ^3.3.2
    bblanchon/ArduinoJson @ ^7.0.0
    adafruit/Adafruit PWM Servo Driver Library @ ^3.0.1
    adafruit/Adafruit BNO08x @ ^1.2.5
    robtillaart/INA226 @ ^0.6.0
```

> **Note :** Les bibliothèques `ESPAsyncWebServer` et `AsyncTCP` utilisent le fork maintenu par `mathieucarbou` (compatible ESP32 Arduino Core récent). L'ancien dépôt `me_no-dev` est obsolète et provoque des erreurs de linking.

> **Table de partitions personnalisée (`bob_control_8mb.csv`) :** dérivée de `default_8MB.csv` — partitions applicatives OTA réduites de 3,3 Mo à **2,5 Mo** chacune (firmware ~1,2 Mo) au profit de LittleFS, étendu de 1,5 Mo à **~2,9 Mo** pour héberger le modèle 3D du ROV (`data/3D/bob_rov_3D.glb`, servi sur `/3D/bob_rov_3D.glb` avec le MIME `model/gltf-binary` via une route explicite — l'extension `.glb` est inconnue de la table MIME du core Arduino) ainsi que three.js (`data/vendor/three.min.js`, r128 UMD licence MIT). **Toute modification de la table de partitions impose un reflash complet par USB** : `pio run -t erase && pio run -t upload && pio run -t uploadfs` — la table (offset 0x8000) ne peut pas être écrite par OTA.

---

## 📂 Structure du Répertoire

```
BOB-CONTROL/
├── README.md                  # Résumé du projet (GitHub)
├── BOBCONTROL.md              # Spécification et documentation (ce fichier)
├── PROTOCOLE_RPI5.md          # Protocole série RPi 5 : trames octet par octet + exemple Python
├── platformio.ini             # Configuration PlatformIO
├── data/                      # Fichiers LittleFS (interface Web)
│   ├── index.html             # Tableau de bord (tuiles + sections)
│   ├── style.css              # Thème sombre BOB CNC + drag & drop
│   └── app.js                 # WebSocket, navigation, drag & drop
├── include/
│   ├── config.h               # Broches, adresses I2C, UART, constantes réseau
│   ├── protocol.h             # Structures de trames packed + CRC16-CCITT + constantes MODE_*
│   ├── autopilot.h            # Structures PIDParams (Roll/Pitch/Yaw/Depth), AutopilotConfig, pidCompute()
│   ├── flight_controller.h    # Classe FlightController : modes PID, mixage moteur, priorité RPi5/Web
│   ├── motor_manager.h        # Classe MotorManager : check propulseurs, surveillance surintensité, NVS (v1.1.0)
│   ├── i2c_router.h           # Routeur I2C Plug & Play : carte module → bus + adresse, NVS, conflits (v1.3.0)
│   └── gpio_outputs.h         # 4 sorties tout-ou-rien ON/OFF : pins NVS, init OFF, état relu
└── src/
    ├── main.cpp               # Setup séquentiel + tâche vTaskControl (Core 1, 100 Hz) + corrections PID
    ├── web_server.cpp         # Serveur HTTP, DNS captif OS-aware, WebSocket, REST API
    ├── serial_comm.cpp        # USB-CDC / UART GPIO : abstraction Stream*, machine à états, watchdog failsafe
    ├── i2c_router.cpp         # Routeur I2C Plug & Play : carte NVS module→bus/adresse chargée au boot, conflits, save() vérifiée par relecture (v1.3.0)
    ├── sensor_driver.cpp      # Drivers I2C réels — chaque capteur sur SON bus routé (BNO085, INA3221, INA226 ×2, MS5803/MS5837)
    ├── flight_controller.cpp  # PID 4 axes (Roll/Pitch/Yaw/Depth) + mixage M5-M8 + gestion priorité maître
    ├── pwm_controller.cpp     # PCA9685 (bus I2C routé) : conversion µs→ticks, typage canaux 10-15, failsafe + mode Témoin (Dry-Run) + isolement moteurs/remontée d'urgence (v1.1.0)
    ├── motor_manager.cpp      # Check propulseurs au démarrage, surveillance surintensité, identification/isolation (v1.1.0)
    └── gpio_outputs.cpp       # 4 sorties ON/OFF : masque gpio_cmd, relecture pad, persistance NVS des broches
```

---

## 🔧 Commandes de Téléversement

```bash
# Téléverser le firmware
pio run -t upload

# Téléverser les fichiers web (LittleFS)
pio run -t uploadfs

# Moniteur série debug (USB-CDC)
pio device monitor -b 115200
```

---
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

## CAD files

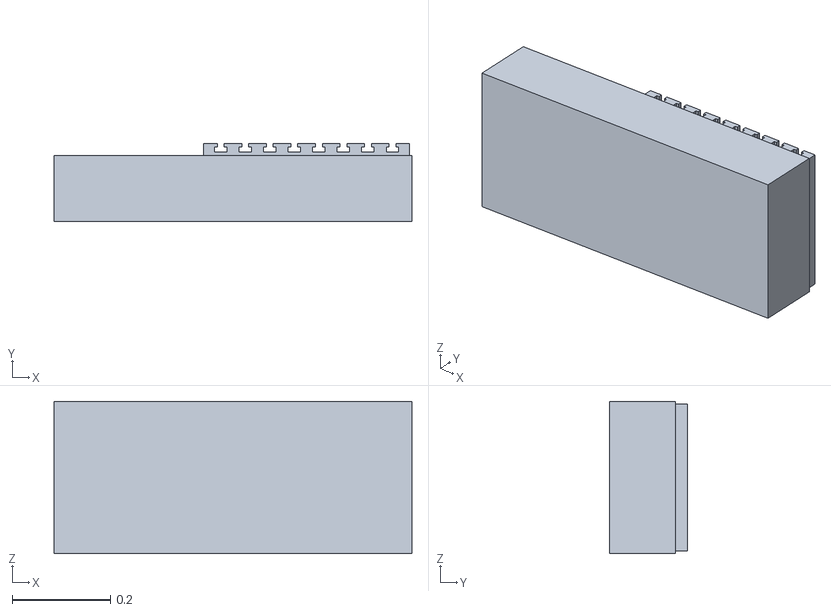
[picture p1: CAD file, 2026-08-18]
exemple BOBCNC/data/BATITCNC.stl
0.73 x 0.16 x 0.31

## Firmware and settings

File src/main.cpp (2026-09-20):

/**
 * @file main.cpp
 * @brief Point d'entrée du firmware BOB-CONTROL pour ESP32-S3.
 *
 * Initialise l'ensemble des périphériques (LittleFS, I2C, Serial, PCA9685),
 * instancie les mutex FreeRTOS et crée les tâches réparties sur les deux cœurs :
 *
 * - Core 0 (Wi-Fi)  : vTaskWeb (serveur HTTP, WebSocket, DNS captif)
 * - Core 1 (RT)     : vTaskControl (boucle de contrôle PWM + failsafe)
 *                     vTaskSensors (acquisition capteurs / simulation)
 *
 * La tâche SerialRx (réception trame) est lancée par SerialComm::begin()
 * et la tâche SerialTx (émission télémétrie) également.
 *
 * @author Didier Dero
 * @version 1.8.0
 * @date Septembre 2026
 */

#include <Arduino.h>
#include <LittleFS.h>
#include <Preferences.h>

#include "config.h"
#include "protocol.h"
#include "autopilot.h"
#include "sensor_driver.h"
#include "pwm_controller.h"
#include "gpio_outputs.h"
#include "serial_comm.h"
#include "web_server.h"
#include "flight_controller.h"
#include "motor_manager.h"      /* g_motors : check/surveillance/isolation (v1.1.0) */
#include "status_io.h"          /* g_statusIo : bandeau LED WS2812 + entrées GPIO (v1.6.0) */
#include "audio_manager.h"      /* g_audio : mélodie de démarrage buzzer LEDC (v1.8.0) */
#include "git_version.h"        /* GIT_VERSION : version Git injectée au build (scripts/git_version.py) */

/* =========================================================================
 * VARIABLES GLOBALES PARTAGÉES
 * ========================================================================= */

/**
 * @brief Mutex protégeant l'accès à la configuration autopilote.
 *
 * La structure AutopilotConfig est lue par la tâche Control
 * et modifiée par le serveur Web via l'onglet Paramètres.
 */
static SemaphoreHandle_t g_mutexConfig = nullptr;

/**
 * @brief Configuration autopilote active (PID + watchdog).
 *
 * Initialisée avec les valeurs par défaut au démarrage, puis
 * restaurée depuis la NVS si des paramètres sauvegardés existent.
 */
static AutopilotConfig g_apConfig;

/* =========================================================================
 * PERSISTANCE NVS (PARAMÈTRES AUTOPILOTE)
 * ========================================================================= */

/**
 * @brief Sauvegarde la configuration autopilote en NVS.
 *
 * Utilise la bibliothèque Preferences (NVS) pour stocker les gains PID
 * et le timeout du watchdog de manière persistante.
 */
static void saveAutopilotConfig() {
    Preferences prefs;
    prefs.begin("autopilot", false);

    /* PID Roll */
    prefs.putFloat("r_kp", g_apConfig.roll.kp);
    prefs.putFloat("r_ki", g_apConfig.roll.ki);
    prefs.putFloat("r_kd", g_apConfig.roll.kd);

    /* PID Pitch */
    prefs.putFloat("p_kp", g_apConfig.pitch.kp);
    prefs.putFloat("p_ki", g_apConfig.pitch.ki);
    prefs.putFloat("p_kd", g_apConfig.pitch.kd);

    /* PID Yaw */
    prefs.putFloat("y_kp", g_apConfig.yaw.kp);
    prefs.putFloat("y_ki", g_apConfig.yaw.ki);
    prefs.putFloat("y_kd", g_apConfig.yaw.kd);

    /* PID Altitude */
    prefs.putFloat("d_kp", g_apConfig.alt.kp);
    prefs.putFloat("d_ki", g_apConfig.alt.ki);
    prefs.putFloat("d_kd", g_apConfig.alt.kd);

    /* Watchdog timeout */
    prefs.putUInt("wdg_ms", g_apConfig.watchdog_ms);

    prefs.end();
    Serial.println("[MAIN] Configuration autopilote sauvegardée en NVS");
}

/**
 * @brief Restaure la configuration autopilote depuis la NVS.
 *
 * Si aucune donnée n'est trouvée, les valeurs par défaut sont conservées.
 */
static void loadAutopilotConfig() {
    Preferences prefs;
    prefs.begin("autopilot", true);  /* Lecture seule */

    /* Vérifier si des données existent (clef "r_kp" comme marqueur) */
    if (!prefs.isKey("r_kp")) {
        prefs.end();
        Serial.println("[MAIN] Aucune config NVS trouvée → valeurs par défaut");
        return;
    }

    /* PID Roll */
    g_apConfig.roll.kp = prefs.getFloat("r_kp", g_apConfig.roll.kp);
    g_apConfig.roll.ki = prefs.getFloat("r_ki", g_apConfig.roll.ki);
    g_apConfig.roll.kd = prefs.getFloat("r_kd", g_apConfig.roll.kd);

    /* PID Pitch */
    g_apConfig.pitch.kp = prefs.getFloat("p_kp", g_apConfig.pitch.kp);
    g_apConfig.pitch.ki = prefs.getFloat("p_ki", g_apConfig.pitch.ki);
    g_apConfig.pitch.kd = prefs.getFloat("p_kd", g_apConfig.pitch.kd);

    /* PID Yaw */
    g_apConfig.yaw.kp = prefs.getFloat("y_kp", g_apConfig.yaw.kp);
    g_apConfig.yaw.ki = prefs.getFloat("y_ki", g_apConfig.yaw.ki);
    g_apConfig.yaw.kd = prefs.getFloat("y_kd", g_apConfig.yaw.kd);

    /* PID Altitude */
    g_apConfig.alt.kp = prefs.getFloat("d_kp", g_apConfig.alt.kp);
    g_apConfig.alt.ki = prefs.getFloat("d_ki", g_apConfig.alt.ki);
    g_apConfig.alt.kd = prefs.getFloat("d_kd", g_apConfig.alt.kd);

    /* Watchdog */
    g_apConfig.watchdog_ms = prefs.getUInt("wdg_ms", SERIAL_TIMEOUT_DEFAULT_MS);

    prefs.end();
    Serial.println("[MAIN] Configuration autopilote restaurée depuis NVS");
}

/* =========================================================================
 * TÂCHE FREERTOS : vTaskControl
 * ========================================================================= */

/**
 * @brief Tâche de contrôle principale (Core 1 - Temps Réel).
 *
 * Boucle à 100 Hz qui :
 * 1. Vérifie le watchdog série (failsafe neutre si timeout)
 * 2. Lit les trames descendantes reçues du RPi 5
 * 3. Applique les consignes PWM et le masque GPIO aux actionneurs
 * 4. Construit la trame montante de télémétrie
 * 5. Met à jour le buffer d'émission série
 *
 * @param param Non utilisé.
 */
static void vTaskControl(void* param) {
    TickType_t lastWake = xTaskGetTickCount();

    for (;;) {
        /* ---- 0. Sécurité voie d'eau (entrée GPIO) ----
         * Tant que l'entrée « Détecteur Voie d'eau » est active (GND ou
         * +3,3 V selon la polarité configurée), l'override force le Retour
         * Surface : le bit MODE_BIT_SURFACE est superposé à chaque setMode()
         * (y compris les trames descendantes RPi 5 à 100 Hz) et le bit
         * STATUS_BIT_SURFACE (0x80) remonte automatiquement via
         * isSurfaceReturnActive(). */
        g_flightCtrl.setSurfaceOverride(g_statusIo.isWaterAlarm());

        /* ---- 1. Vérification du watchdog série ---- */
        if (g_serial.isWatchdogTriggered()) {
            /* Le watchdog a déjà forcé le neutre dans serial_comm.cpp */
            /* On continue de boucler pour maintenir la télémétrie */
        }

        /* ---- 2. Traitement d'une nouvelle trame descendante ---- */
        if (g_serial.hasNewFrame()) {
            DownlinkData dl;
            g_serial.getDownlinkData(dl);

            /* Vérification de l'état d'armement */
            if (dl.arm_state == ARM_ESTOP) {
                /* Arrêt d'urgence : tous les canaux au neutre + sorties ON/OFF à OFF.
                 * La remontée d'urgence est d'abord coupée : l'E-Stop est une
                 * décision humaine qui PRIME sur la survie automatique (v1.1.0). */
                g_motors.abortEmergencySurface();
                g_pwm.setAllNeutral();
                g_gpio.allOff();
                g_flightCtrl.resetPID();
            } else if (dl.arm_state == ARM_ARMED) {
                /* Armé : appliquer les consignes PWM brutes du RPi 5 */
                g_pwm.setAllPWM(dl.pwm);
                /* Sorties tout-ou-rien : masque gpio_cmd de la trame */
                g_gpio.applyCommand(dl.gpio_cmd);
                /* Notifier le contrôleur de vol du mode RPi 5 */
                g_flightCtrl.updateFromRPi5(dl.mode);
            } else {
                /* Désarmé : neutre sur tous les propulseurs (0-7) */
                for (uint8_t i = 0; i < 8; i++) {
                    g_pwm.setPWMuS(i, PWM_NEUTRAL_US);
                }
                /* Servos et auxiliaires acceptent les commandes même désarmés */
                for (uint8_t i = 8; i < NUM_PWM_CHANNELS; i++) {
                    g_pwm.setPWMuS(i, dl.pwm[i]);
                }
                /* Sorties tout-ou-rien : pilotables même désarmé (auxiliaires) */
                g_gpio.applyCommand(dl.gpio_cmd);
                g_flightCtrl.resetPID();
            }
        }

        /* ---- 2b. Corrections PID du contrôleur de vol ---- */
        {
            uint8_t mode = g_flightCtrl.getActiveMode();
            if (mode != MODE_PASSIF) {
                /* Récupérer les consignes PWM actuelles */
                uint16_t pwmOut[NUM_PWM_CHANNELS];
                g_pwm.getCurrentValues(pwmOut);

                /* Si aucun RPi 5 maître, forcer les propulseurs à 1500µs
                 * (validation sur établi sans trame descendante) */
                if (!g_flightCtrl.isRPi5Master()) {
                    for (uint8_t i = 0; i < 8; i++) {
                        pwmOut[i] = PWM_NEUTRAL_US;
                    }
                }

                /* Appliquer les corrections PID + mixage */
                IMUData imuCtl;
                g_sensors.getIMUData(imuCtl);
                PressureData pressCtl;
                g_sensors.getPressureData(pressCtl);
                float dt = (float)TASK_CONTROL_PERIOD_MS / 1000.0f;
                g_flightCtrl.update(imuCtl, pressCtl, pwmOut, 8, dt);
                g_pwm.setAllPWM(pwmOut);
            }
        }

        /* ---- 2c. VERROU SÉCURITÉ « FLUX IMU MORT » (watchdog BNO085) ----
         *      Tant que le flux de quaternions est mort (capteur en cours de
         *      récupération niveaux 1/2, ou imminence du niveau 3), les
         *      propulseurs sont FORCÉS au neutre à CHAQUE cycle : une consigne
         *      RPi 5 réappliquée entre deux tentatives ne peut jamais repartir
         *      avec une attitude inconnue. Servos/auxiliaires (8-15) exclus. ---- */
        if (g_sensors.isBNO085Stalled()) {
            for (uint8_t i = 0; i < 8; i++) {
                g_pwm.setPWMuS(i, PWM_NEUTRAL_US);
            }
        }

        /* ---- 3. Construction de la trame montante de télémétrie ---- */
        UplinkFrame_t ul;
        ul.header1 = UL_HEADER_1;    /* 0x55 */
        ul.header2 = UL_HEADER_2;    /* 0xAA */
        ul.type    = UL_FRAME_TYPE;  /* 0x02 */

        /* Bits de statut — supervision des boucles réellement actives (v1.4.0) */
        ul.status = 0;
        if (g_serial.getLastFrameTime() > 0)      ul.status |= STATUS_BIT_ARMED;
        if (g_serial.isWatchdogTriggered())       ul.status |= STATUS_BIT_WDG;
        if (!g_pwm.isPhysicalOutputsEnabled())    ul.status |= STATUS_BIT_DRYRUN;
        if (g_flightCtrl.isRollPitchActive())     ul.status |= STATUS_BIT_RT;
        if (g_flightCtrl.isDepthHoldActive())     ul.status |= STATUS_BIT_DEPTH;
        if (g_flightCtrl.isCapHoldActive())       ul.status |= STATUS_BIT_CAP;
        if (g_flightCtrl.isSurfaceReturnActive()) ul.status |= STATUS_BIT_SURFACE;

        /* Données IMU (quaternions et gyroscope) */
        IMUData imu;
        g_sensors.getIMUData(imu);
        memcpy(ul.quat, imu.quat, sizeof(ul.quat));
        memcpy(ul.gyro, imu.gyro, sizeof(ul.gyro));

        /* Pression et température */
        PressureData press;
        g_sensors.getPressureData(press);
        ul.pressure    = press.pressure_mbar;
        ul.temperature = press.temperature;

        /* Télémétrie puissance (3 canaux INA3221 — v1.1.0) : [V_BAT, 0],
         * [signal ACS770 horizontaux mV, courant H mA], [signal ACS770
         * verticaux mV, courant V mA]. Format binaire inchangé (6 slots
         * mV/mA — compatibilité RPi 5) ; les INA226 #2/#3 restent visibles
         * via la télémétrie WebSocket (power[5]). */
        PowerData pwr;
        g_sensors.getPowerData(pwr);
        for (uint8_t i = 0; i < 3; i++) {
            ul.power[i * 2]     = pwr.voltage[i];  /* Tension en mV */
            /* Courant en mA — saturation au plafond du champ binaire 16 bits du
             * protocole RPi 5 (65,5 A ; la plage ACS770-100U va jusqu'à 100 A). */
            ul.power[i * 2 + 1] = (pwr.current[i] > 0xFFFFu)
                                ? (uint16_t)0xFFFFu : (uint16_t)pwr.current[i];
        }

        /* PWM effectifs (valeurs réellement envoyées) */
        g_pwm.getCurrentValues(ul.pwm_actual);

        /* État réel des 4 sorties tout-ou-rien (gpio_state) */
        ul.gpio_state = g_gpio.getState();

        /* Calcul et insertion du CRC16 */
        uint8_t* frameBytes = reinterpret_cast<uint8_t*>(&ul);
        crc16_fill(frameBytes, UL_FRAME_SIZE);

        /* Mise à jour du buffer d'émission série */
        g_serial.updateTelemetry(frameBytes, UL_FRAME_SIZE);

        /* Attente périodique précise (100 Hz) */
        vTaskDelayUntil(&lastWake, pdMS_TO_TICKS(TASK_CONTROL_PERIOD_MS));
    }
}

/* =========================================================================
 * SETUP (INITIALISATION GLOBALE)
 * ========================================================================= */

/**
 * @brief Initialisation globale appelée une seule fois au démarrage.
 *
 * Séquence d'initialisation :
 * 1. Liaison série USB-CDC
 * 2. Filesystem LittleFS (interface Web statique)
 * 3. Configuration autopilote (NVS)
 * 4. Bus I2C et capteurs
 * 5. Contrôleur PWM PCA9685
 * 5b. Sorties tout-ou-rien GPIO ON/OFF (4 sorties, init OFF)
 * 6. Communication série (machine à états)
 * 7. Serveur Web embarqué
 * 8. Tâche de contrôle FreeRTOS
 */
void setup() {
    /* ---- 1. Liaison série USB-CDC pour le debug ---- */
    Serial.begin(115200);
    delay(1000);
    Serial.println("\n==============================================");
    Serial.println("  BOB-CONTROL " GIT_VERSION " - ROV Firmware");
    Serial.println("  ESP32-S3 PlatformIO / FreeRTOS");
    Serial.println("==============================================\n");

    /* ---- 2. Initialisation du filesystem LittleFS ---- */
    if (!LittleFS.begin(true)) {  /* true = formater si nécessaire */
        Serial.println("[MAIN] ERREUR : échec de montage LittleFS !");
    } else {
        Serial.println("[MAIN] LittleFS monté avec succès");
        /* Afficher l'espace disponible */
        Serial.println("[MAIN] LittleFS - Total : " + String(LittleFS.totalBytes())
                       + " octets, Utilisé : " + String(LittleFS.usedBytes()) + " octets");
    }

    /* ---- 3. Configuration autopilote (valeurs par défaut + NVS) ---- */
    g_apConfig = getDefaultAutopilotConfig();
    loadAutopilotConfig();

    /* Création du mutex de protection de la configuration */
    g_mutexConfig = xSemaphoreCreateMutex();

    /* ---- 4. Initialisation des capteurs I2C ---- */
    /* Les broches des DEUX bus (clés NVS i2c_sda/i2c_scl et i2c2_sda/i2c2_scl,
     * défauts GPIO 10/11 et 6/7) sont chargées par SensorDriver::begin() —
     * source unique, qui journalise et configure Wire (bus n°1) et Wire1
     * (bus n°2) d'un seul endroit. */
    g_sensors.begin();

    /* ---- 5. Initialisation du contrôleur PWM PCA9685 ---- */
    g_pwm.begin();

    /* ---- 5b. Initialisation des 4 sorties tout-ou-rien (GPIO ON/OFF) ---- */
    g_gpio.begin();

    /* ---- 6. Initialisation de la communication série (USB-CDC ou UART GPIO) ---- */
    /* Chargement du choix d'interface depuis la NVS */
    SerialInterfaceType commIface = COMM_INTERFACE_USB_CDC;
    {
        Preferences cprefs;
        cprefs.begin("config", true);
        if (cprefs.isKey("comm_iface")) {
            commIface = (SerialInterfaceType)cprefs.getUChar("comm_iface", 0);
        }
        cprefs.end();
        Serial.println("[MAIN] Interface série RPi5 : " + String((uint8_t)commIface) +
                       (commIface == COMM_INTERFACE_UART_GPIO ? " (UART GPIO 1/2)" : " (USB-CDC)"));
    }
    g_serial.begin(commIface);

    /* Appliquer le timeout watchdog depuis la configuration */
    g_serial.setWatchdogTimeout(g_apConfig.watchdog_ms);

    /* ---- 7. Initialisation du serveur Web et portail captif ---- */
    g_webServer.begin();

    /* ---- 7b. Initialisation du contrôleur de vol ---- */
    g_flightCtrl.begin(&g_apConfig, g_mutexConfig);

    /* ---- 7c. Gestion de sécurité moteurs (v1.1.0) ----
     * Tâche dédiée (Core 1) : attente NON BLOQUANTE de la connexion Wi-Fi
     * puis check propulseurs (si l'option NVS est active), surveillance
     * surintensité continue, identification/isolement et remontée d'urgence.
     * Aucune attente dans setup() — le boot reste instantané. */
    g_motors.begin();

    /* ---- 7d. Signalisation LED WS2812 + entrées numériques (v1.6.0) ----
     * Tâche dédiée (Core 0) : échantillonnage anti-rebond des entrées
     * Armement / Voie d'eau (polarité configurable) et rendu non bloquant
     * du bandeau LED selon l'état réel du contrôleur (millis()). Aucune
     * attente ici. */
    g_statusIo.begin();

    /* ---- 7e. Acoustique / buzzer (v1.8.0) ----
     * Charge la configuration NVS du buzzer (GPIO + mélodie de démarrage).
     * N'émet aucun son ici : la mélodie est lancée en toute fin de setup()
     * par une tâche éphémère. */
    g_audio.begin();

    /* ---- 8. Lancement de la tâche de contrôle sur Core 1 ---- */
    xTaskCreatePinnedToCore(
        vTaskControl,           /* Fonction de la tâche */
        "Control",              /* Nom */
        STACK_SIZE_CONTROL,     /* Taille de stack (4096 octets) */
        nullptr,                /* Paramètre */
        PRIORITY_CONTROL,       /* Priorité maximale (5) */
        nullptr,                /* Handle */
        CORE_RT                 /* Core 1 (temps réel) */
    );

    /* ---- 9. Signature sonore de démarrage (v1.8.0) ----
     * Si la mélodie est cochée en NVS et qu'un GPIO de buzzer est assigné,
     * la lecture des 5 notes (« Rencontres du 3ème type ») est encapsulée
     * dans une tâche FreeRTOS éphémère (Core 0, priorité basse) qui se
     * détruit après la dernière note : ce setup() n'attend jamais et la
     * télémétrie 100 Hz du Core 1 n'est pas retardée. */
    g_audio.playStartupMelodyIfEnabled();

    Serial.println("[MAIN] Initialisation complète - système opérationnel\n");
}

/* =========================================================================
 * LOOP (INACTIF - TOUT EST GÉRÉ PAR FREERTOS)
 * ========================================================================= */

/**
 * @brief Boucle Arduino principale (inutilisée).
 *
 * Toute la logique est déléguée aux tâches FreeRTOS.
 * La boucle loop() reste vide pour éviter la contention CPU.
 */
void loop() {
    vTaskDelay(pdMS_TO_TICKS(10000));  /* Suspension longue durée */
}

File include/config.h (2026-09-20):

/**
 * @file config.h
 * @brief Configuration matérielle globale du projet BOB-CONTROL.
 *
 * Ce fichier centralise l'ensemble des constantes matérielles, adresses I2C,
 * assignations de broches, paramètres réseau, fréquences de tâches FreeRTOS,
 * énumérations de capteurs et profils HAL pour le contrôleur ROV.
 *
 * @author Didier Dero
 * @version 1.1.0
 * @date Août 2026
 * @copyright MIT License
 */

#ifndef CONFIG_H
#define CONFIG_H

#include <stdint.h>

/* =========================================================================
 * SECTION 1 : CONFIGURATION I2C — DEUX BUS MATÉRIELS
 *
 * Répartition PAR DÉFAUT des modules (v1.2.0 : routage dynamique Plug & Play,
 * chaque module est réassignable aux deux bus depuis l'interface Web — voir
 * i2c_router.h/.cpp, clés NVS « route_* ») :
 *
 * Bus n°1 (Wire,  GPIO 10/11) : BNO085 + INA3221 + 2× INA226 — propriété
 *                              exclusive de la tâche capteurs (Core 1).
 * Bus n°2 (Wire1, GPIO 6/7)   : MS5837 + PCA9685 — broches par défaut,
 *                              configurables en NVS (page Paramètres) ;
 *                              partagé entre la tâche capteurs (pression
 *                              2 Hz) et la tâche de contrôle (PWM 100 Hz) ;
 *                              chaque transaction est atomique et sérialisée
 *                              par le verrou interne de Wire1 (un par
 *                              instance TwoWire).
 *
 * Historique : le MS5837-30BA branché sur le même bus que le BNO085
 * perturbait ses lectures SHTP (tempête de NACK → horizon figé) — d'où la
 * séparation physique sur les deux contrôleurs I2C de l'ESP32-S3.
 * Chaque bus possède ses propres résistances de pull-up (4,7 kΩ vers 3V3).
 * ========================================================================= */

/** @brief Broche SDA du bus I2C n°1 — BNO085 + 3× INA226 (GPIO 10) */
constexpr uint8_t  I2C_SDA_PIN          = 10;

/** @brief Broche SCL du bus I2C n°1 — BNO085 + 3× INA226 (GPIO 11) */
constexpr uint8_t  I2C_SCL_PIN          = 11;

/** @brief Broche SDA du bus I2C n°2 — défaut GPIO 6 (clé NVS « i2c2_sda ») */
constexpr uint8_t  I2C_BUS2_SDA_PIN     = 6;

/** @brief Broche SCL du bus I2C n°2 — défaut GPIO 7 (clé NVS « i2c2_scl ») */
constexpr uint8_t  I2C_BUS2_SCL_PIN     = 7;

/**
 * @brief Fréquence du bus I2C en Hz (400 kHz Fast Mode).
 *
 * Valeur de la version de référence fonctionnelle (BNO085 + MS5803 + INA226
 * + PCA9685 stables). Un passage expérimental à 100 kHz avait coïncidé avec
 * des échecs d'initialisation du BNO085 — non retenu.
 */
constexpr uint32_t I2C_FREQ_HZ         = 400000UL;

/** @brief Numéro du port I2C matériel utilisé */
constexpr int      I2C_PORT_NUM         = 0;

/**
 * @brief Timeout matériel I2C en ms (>= 50 ms).
 * Laisse au coprocesseur ARM du BNO085 le temps d'étirer l'horloge pendant ses
 * traitements internes, sans abandonner prématurément la transaction.
 */
constexpr uint32_t I2C_TIMEOUT_MS      = 50UL;

/** @brief Délai de boot BNO085 (ms) avant la 1re commande I2C après mise sous tension */
constexpr uint32_t BNO085_BOOT_DELAY_MS = 1000UL;  /* le coprocesseur ARM du BNO085 démarre en ~1 s */

/** @brief Nombre maximal de tentatives d'initialisation du BNO085 */
constexpr uint8_t  BNO085_INIT_MAX_ATTEMPTS = 5;

/** @brief Délai (ms) entre deux tentatives d'initialisation du BNO085 */
constexpr uint32_t BNO085_INIT_RETRY_DELAY_MS = 200UL;

/** @brief Nombre max de rapports SH-2 lus par interrogation (borne la boucle de drain) */
constexpr uint8_t  BNO085_MAX_EVENTS_PER_READ = 8;

/**
 * @brief Timeout (ms) sans donnée BNO085 avant auto-récupération.
 * Si le capteur est connecté mais ne renvoie plus aucun rapport (bus bloqué,
 * ESP_ERR_INVALID_STATE après NACK), on tente une ré-init du capteur puis, si
 * besoin, une réinitialisation logicielle propre du bus I2C.
 */
constexpr uint32_t BNO085_STALL_TIMEOUT_MS = 1000UL;

/**
 * @brief Fraîcheur maximale (ms) du Rotation Vector pour rester source de cap.
 *
 * Au-delà (rapport magnétique jamais activé ou flux interrompu), le Game
 * Rotation Vector (relatif, sans magnéto) prend le relais comme source de cap.
 */
constexpr uint32_t BNO085_MAG_STALE_MS = 200UL;

/**
 * @brief Récupération BNO085 : nombre de tentatives douces avant reset bus direct.
 *
 * Les premières récupérations restent légères (ré-init SHTP du seul capteur) ;
 * dès que les échecs s'enchaînent, on passe d'emblée au reset complet du bus.
 */
constexpr uint8_t  BNO085_STREAK_BUS_RESET = 2;
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

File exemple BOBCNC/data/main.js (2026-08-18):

/**
 * ============================================
 * FICHIER JAVASCRIPT - ANIMATIONS GSAP
 * Style inspire CodePen avec effets avances
 * ============================================
 */

// Polyfill GSAP minimal pour le mode hors-ligne (ESP32 sans Internet)
// Les animations sont simplement ignorees au lieu de crasher.
if (typeof gsap === 'undefined') {
    window.gsap = {
        to:        function() { return arguments[0]; },
        fromTo:    function() { return arguments[0]; },
        from:      function() { return arguments[0]; },
        set:       function() {},
        registerPlugin: function() {},
        timeline:  function() { return { to:function(){return this;}, fromTo:function(){return this;}, from:function(){return this;} }; }
    };
    console.warn('[BOBCNC] GSAP CDN indisponible (mode hors-ligne) - animations desactivees');
}

// ============================================================
//  BOBCNC SETTINGS GLOBAUX (Start / End G-code)
//  Source unique : /bobcnc_settings.json sur LittleFS de l'ESP32-S3
//  BOBCNC. AUCUN stockage localStorage : la persistance est physique
//  sur la flash de la carte BOBCNC, indépendante de FluidNC.
// ============================================================
window.bobcncSettings = window.bobcncSettings || {
    startGcode: '',
    endGcode:   '',
    loaded:     false
};

// Charge les Start/End G-code depuis l'ESP32 (GET /api/settings)
window.loadBobcncSettings = function() {
    return fetch('/api/settings', { cache: 'no-store' })
        .then(function(r) { return r.ok ? r.json() : Promise.reject(r.status); })
        .then(function(data) {
            window.bobcncSettings.startGcode = (data && typeof data.startGcode === 'string') ? data.startGcode : '';
            window.bobcncSettings.endGcode   = (data && typeof data.endGcode   === 'string') ? data.endGcode   : '';
            window.bobcncSettings.loaded     = true;
            return window.bobcncSettings;
        })
        .catch(function(err) {
            console.warn('[BOBCNC] /api/settings indisponible :', err);
            window.bobcncSettings.loaded = true; // évite de bloquer indéfiniment
            return window.bobcncSettings;
        });
};

// Sauvegarde les Start/End G-code sur l'ESP32 (POST /api/settings)
window.saveBobcncSettings = function(startGcode, endGcode) {
    var payload = {
        startGcode: typeof startGcode === 'string' ? startGcode : '',
        endGcode:   typeof endGcode   === 'string' ? endGcode   : ''
    };
    return fetch('/api/settings', {
        method: 'POST',
        headers: { 'Content-Type': 'application/json' },
        body: JSON.stringify(payload)
    }).then(function(r) {
        if (!r.ok) throw new Error('HTTP ' + r.status);
        return r.json();
    }).then(function(j) {
        if (j && j.success) {
            window.bobcncSettings.startGcode = payload.startGcode;
            window.bobcncSettings.endGcode   = payload.endGcode;
            window.bobcncSettings.loaded     = true;
        }
        return j;
    });
};

/**
 * Encapsule un G-code généré ("core") avec le Start G-code en tête
 * et le End G-code en queue. Retourne la chaîne complète à envoyer
 * à FluidNC. Si les paramètres ne sont pas chargés ou vides, le
 * core est renvoyé tel quel.
 */
window.wrapWithStartEndGcode = function(coreGcode) {
    if (typeof coreGcode !== 'string' || coreGcode.length === 0) {
        return coreGcode || '';
    }
    var s = (window.bobcncSettings && typeof window.bobcncSettings.startGcode === 'string')
            ? window.bobcncSettings.startGcode.replace(/\r\n/g, '\n').trim() : '';
    var e = (window.bobcncSettings && typeof window.bobcncSettings.endGcode === 'string')
            ? window.bobcncSettings.endGcode.replace(/\r\n/g, '\n').trim() : '';
    if (!s && !e) return coreGcode;
    var parts = [];
    if (s) {
        parts.push('(===== START G-CODE BOBCNC =====)');
        parts.push(s);
        parts.push('(===== FIN START G-CODE =====)');
        parts.push('');
    }
    parts.push(coreGcode);
    if (e) {
        parts.push('');
        parts.push('(===== END G-CODE BOBCNC =====)');
        parts.push(e);
        parts.push('(===== FIN END G-CODE =====)');
    }
    return parts.join('\n');
};

// Chargement automatique au démarrage de toute page incluant main.js
document.addEventListener('DOMContentLoaded', function() {
    if (typeof window.loadBobcncSettings === 'function') {
        window.loadBobcncSettings();
    }
});
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

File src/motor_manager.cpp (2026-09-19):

/**
 * @file motor_manager.cpp
 * @brief Implémentation de la gestion de sécurité moteurs (v1.1.0).
 *
 * Check Propulseurs au démarrage (après connexion Wi-Fi non bloquante),
 * surveillance continue des courants ACS770 (INA3221 canaux 2/3),
 * identification + isolement logique du moteur en surintensité, et remontée
 * d'urgence optionnelle avec les verticaux restants.
 *
 * Discipline de sûreté :
 *  - AUCUNE écriture moteur hors des garde-fous existants : les impulsions du
 *    check utilisent g_pwm.setPWMuS() (bornage + buffer + Dry-Run), le retour
 *    au neutre passe par setPWMuS(channel, PWM_NEUTRAL_US) canal par canal —
 *    jamais de setAllNeutral() qui écraserait les servos 8-15 ;
 *  - le watchdog série ne force le neutre qu'UNE fois, à la transition de
 *    timeout, et seulement si une trame RPi 5 a déjà été reçue : au boot
 *    (aucune trame), il ne perturbe jamais la séquence de check ;
 *  - les lectures I2C du check passent par SensorDriver::readACS770CurrentmA()
 *    qui prend le verrou _bus1Lock partagé avec la tâche capteurs ;
 *  - Dry-Run : les impulsions restent dans le buffer (aucun mouvement
 *    physique) mais la logique de mesure s'exécute quand même — utile pour
 *    valider la chaîne de mesure sur établi.
 *
 * @author Didier Dero
 * @version 1.1.0
 */

#include "motor_manager.h"
#include "sensor_driver.h"
#include "pwm_controller.h"
#include "web_server.h"

#include <Preferences.h>
#include <math.h>

/* =========================================================================
 * INSTANCE GLOBALE
 * ========================================================================= */

/** @brief Instance globale du gestionnaire de sécurité moteurs */
MotorManager g_motors;

/* =========================================================================
 * CONSTRUCTEUR
 * ========================================================================= */

MotorManager::MotorManager()
    : _health(MOTOR_HEALTH_UNKNOWN)
    , _checkDone(false)
    , _checkPassed(false)
    , _checkRequested(false)
    , _resetRequested(false)
    , _autoArmed(false)
    , _sequenceRunning(false)
    , _faultActive(false)
    , _emergencyActive(false)
    , _isolatedMask(0)
    , _overcurrentStreakH(0)
    , _overcurrentStreakV(0)
    , _mutex(nullptr)
{
    _cfg.checkEnable       = true;                          /* défauts ON */
    _cfg.detectEnable      = true;
    _cfg.emergencyEnable   = false;
    _cfg.currentThresholdA = MOTOR_CURRENT_THRESH_DEFAULT_A;
    _cfg.vbatLowV          = MOTOR_VBAT_LOW_DEFAULT_V;
    _lastStatus[0]         = '\0';
}

/* =========================================================================
 * INITIALISATION
 * ========================================================================= */

void MotorManager::begin() {
    _mutex = xSemaphoreCreateMutex();

    /* Configuration NVS (namespace « motors ») — chaque lecture retombe sur
     * les défauts config.h si la clé est absente (première utilisation). */
    Preferences prefs;
    prefs.begin("motors", true);
    _cfg.checkEnable       = prefs.getBool("check_enable", true);
    _cfg.detectEnable      = prefs.getBool("detect_enable", true);
    _cfg.emergencyEnable   = prefs.getBool("emergency_enable", false);
    _cfg.currentThresholdA = prefs.getFloat("cur_thresh", MOTOR_CURRENT_THRESH_DEFAULT_A);
    _cfg.vbatLowV          = prefs.getFloat("vbat_low", MOTOR_VBAT_LOW_DEFAULT_V);
    prefs.end();

    /* Bornage défensif : une NVS corrompue ne doit jamais produire un seuil
     * absurde (0 A déclencherait en permanence, 100 A jamais). */
    if (_cfg.currentThresholdA < MOTOR_CURRENT_THRESH_MIN_A) _cfg.currentThresholdA = MOTOR_CURRENT_THRESH_MIN_A;
    if (_cfg.currentThresholdA > MOTOR_CURRENT_THRESH_MAX_A) _cfg.currentThresholdA = MOTOR_CURRENT_THRESH_MAX_A;
    if (_cfg.vbatLowV < MOTOR_VBAT_LOW_MIN_V) _cfg.vbatLowV = MOTOR_VBAT_LOW_MIN_V;
    if (_cfg.vbatLowV > MOTOR_VBAT_LOW_MAX_V) _cfg.vbatLowV = MOTOR_VBAT_LOW_MAX_V;

    /* Armement du check automatique, FIGÉ au boot : activer l'option à chaud
     * depuis l'interface ne déclenche JAMAIS d'impulsions en navigation —
     * seule la relance manuelle (bouton Paramètres) teste à chaud. */
    _autoArmed = _cfg.checkEnable;
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

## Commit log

2026-08-18 feat: Initial commit - BOB-CONTROL ESP32-S3 firmware with flight modes and Web UI
    [BATITCNC.stl, atc.csv, outils.csv]
2026-08-18 feat: per-sensor simulation, I2C bus protection, BMP280 NORMAL mode fix
    - Replace global _simMode with 3 independent flags: _simIMU, _simPressure, _simPower
    - Default to RÉEL mode; auto-switch to SIM only for undetected sensors
    - Add _i2cBusy flag to prevent I2C bus contention between Core 0 and Core 1
    - Add I2C bus recovery (9 SCL clock pulses + STOP condition) before scan
    - Reduce Wire timeout to 10ms during scan (< 1.3s total)
    - Fix BMP280/BME280: mode FORCED (0x25) → NORMAL (0x27) + IIR filter x4
    - API /api/mode accepts per-sensor params: imu, pressure, power
    - Telemetry: sim_imu, sim_pressure, sim_power fields
    - UI: 3 toggle buttons (MPU9250/BME280/INA226) replacing single toggle
    - C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
    [app.js, sensor_driver.cpp, web_server.cpp]
2026-09-05 feat: altitude barométrique, VSI, modes de pilotage étendus, BNO085 via Adafruit BNO08x
    - Remplacement profondeur par altitude barométrique (BMP280)
    - Ajout variomètre VSI en cm/s à gauche de l'horizon artificiel
    - Mode AUTO_ROULIS étendu au tangage (roll + pitch)
    - Reconfiguration BMP280 pour ODR 40 Hz (standby 0.5ms, IIR ×4)
    - Intégration BNO085 via bibliothèque Adafruit BNO08x (protocole SH-2)
    - Mixage Yaw supprimé sur verticaux (M5-M8), configuration X horizontaux
    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
2026-09-09 refactor: nettoyage capteurs/simulation + fix réorganisation tuiles
    - Suppression MPU9250, AK8963 (magnéto), BME280/BMP280 : BNO085 seule IMU
    - MS5803 conservé comme baromètre unique (renommé MS5803 / MS5837)
    - Suppression de toute la simulation (isSimMode, toggles, télémétrie sim, STATUS_BIT_SIMU)
    - Suppression du Forçage Cap Manuel (heading_override, bouton Tare Nord)
    - Librairies retirées de platformio.ini (BME280, BMP280, MPU9250)
    - Fix drag & drop des tuiles : blocage du drag natif des ancres <a href>
    (dragstart preventDefault + setPointerCapture + nextElementSibling + user-drag:none)
    - Documentation mise à jour (BOBCONTROL.md v2.0.0, README.md)
    [app.js, config.h, main.cpp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]
2026-09-09 perf(web): rendu télémétrie découplé + caches DOM ; suppression brouillon BOBCONTROLE.md
    - onmessage découplé via requestAnimationFrame (anti-accumulation : fin des handlers ~800 ms)
    - caches getEl/getCtx : plus de getElementById/getContext répétés à 20 Hz
    - rendu conditionnel (PWM, schéma ROV, badges, modes) : écriture seulement si la valeur change
    - boucle aviation auto-stop à convergence (plus de redraw canvas 60×/s au repos)
    - suppression de BOBCONTROLE.md (brouillon obsolète v1.0.0, doublon de BOBCONTROL.md)
2026-09-09 feat(sensors/web): MS5803 ROV — tare surface, profondeur/immersion, VSI corrigé
    Backend (MS5803) :
    - Throttle 2 Hz + conversion ADC hors mutex (corrige le gel de la télémétrie
    WebSocket/PID causé par les delay() bloquants sous mutex).
    - Tare de la pression de surface (P_surface) au boot + commande WS tare_surface.
    - Détection surface/immersion (seuil ΔP > 15 mbar) : profondeur eau douce
    (ΔP·100/(ρ·g)) en immersion, altitude barométrique internationale hors de l'eau.
    - PressureData étendu (surface_mbar, depth_m, baro_alt_m, immersed) ; télémétrie
    JSON enrichie ; altitude_m (repère PID) conservé.
    Interface web :
    - Carte « Pression / Profondeur » : statut, surface (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
    [app.js, config.h, sensor_driver.cpp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]
2026-09-16 feat(sensors/web): cap magnétique BNO085 remappé à la source, double bus I2C, OTA et ROV 3D temps réel
    Capteurs :
    - BNO085 : Rotation Vector 9-DOF (cap magnétique absolu) source principale,
    Game Rotation Vector en secours automatique, gyroscope calibré @ 50 Hz ;
    montage physique tourné de 90° remappé À LA SOURCE (quaternion + gyroscope,
    BNO085_MOUNT_YAW_DEG = -90°) → tangage/roulis d'aplomb sur la télémétrie,
    l'horizon artificiel, le HSI, le modèle 3D et le PID (repère véhicule).
    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
    [bob_control_8mb.csv]
2026-09-17 docs(protocol): spécification complète RPi 5 (PROTOCOLE_RPI5.md) + correctif trame montante 71→72 octets
    - PROTOCOLE_RPI5.md (nouveau) : référence unique pour développer le code du
    cockpit Raspberry Pi 5. Trames descendante (39 octets) et montante
    (72 octets) décrites octet par octet (offsets, types, unités, facteurs de
    conversion), sémantique exacte des bits de statut (liaison / watchdog /
    dry-run), règles de sécurité (watchdog 500 ms, armement, priorité maître
    1000 ms, dry-run), mapping des 16 canaux PWM, conversions IMU/pression/
    profondeur, exemple Python pyserial complet et validé hors ligne (CRC,
    vecteurs de test, réassemblage de flux bruité) et section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
2026-09-17 fix(imu): ajout watchdog 3 niveaux BNO085 avec auto-reboot securise et doc
    [config.h, main.cpp, sensor_driver.cpp]
2026-09-17 Release v1.0.1 : Footer dynamique, Jiggle iOS drag&drop, et calibration altimétrique de précision via QNH/Open-Meteo
    Montée de version 1.0.0 -> 1.0.1. Embarque également le travail accumulé
    non versionné des itérations précédentes (sorties GPIO ON/OFF x4, typage
    PWM canaux 10-15, banc de test adaptatif, noms des sorties NVS).
    Version 1.0.1
    -------------
    - Version Git dynamique : script pre-build scripts/git_version.py générant
    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
2026-09-19 feat(ESP32): UI Simulateur, ACS770, accordéons et badge version README
    Évolution du numéro de version (v1.5.0 — tag Git injecté au build via git_version.py).
    Ajout de la version sous le titre dans le README.md.
    Création du panneau latéral off-canvas pour le simulateur de test (masqué sur mobile).
    Mise à jour de la télémétrie pour la double batterie (Propulsion INA3221 / Électronique INA226).
    Correction C++ (sensor_driver.cpp) du calcul de la limite de courant ACS770 (débridé à 80A).
    Animation poussée avec rebond du bouton retour lors de l'ouverture du panneau simulateur.
    Refonte de l'onglet Paramètres en accordéon (balises natives <details>).
    [app.js, config.h, flight_controller.cpp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]
2026-09-19 feat(ESP32): Bump v1.6.0, Bandeau LED WS2812 et Entrées GPIO sécurité
    Évolution du numéro de version (v1.5.0 -> v1.6.0) et mise à jour du badge README.
    Ajout du module status_io pour la gestion des LED et des entrées avec sauvegarde NVS indépendante.
    Intégration du bandeau LED (animations/couleurs configurables selon 5 états du ROV).
    Ajout de l'entrée GPIO "Armement" et "Voie d'eau" (override matériel prioritaire pour le Retour Surface).
    Ajout des accordéons "Signalisation LED" et "Entrées Numériques" dans l'UI des Paramètres.
2026-09-20 feat(ESP32): Bump v1.7.0, Synchro NVS dynamique vers RPi5 (Proto v1.5.0)
    Incrémentation firmware v1.7.0 et validation Protocole v1.5.0.
    Ajout des trames 0x03 (PWM) et 0x04 (TOR) de 27 octets pour la synchro des noms NVS.
    Implémentation de 3 déclencheurs de synchro (Init 0xFF, Reconnexion, Sauvegarde Web UI).
    Envoi asynchrone non-bloquant via SerialTx (1 trame/10ms) pour garantir la télémétrie à 100Hz.
    Mise à jour exhaustive de PROTOCOLE_RPI5.md avec exemples Python et vecteurs de test croisés.
2026-09-20 feat(ESP32): Bump v1.8.0, Signature sonore Rencontres du 3ème type avec volume NVS
    Passage à la version 1.8.0 et mise à jour du badge README.
    Ajout du module audio_manager pour la persistance NVS du buzzer.
    Tâche FreeRTOS non-bloquante (Core 0) pour jouer les 5 notes au démarrage.
    Gestion du volume via le rapport cyclique PWM (API ledc Core 3.2.1).
    Ajout de l'accordéon "Acoustique / Buzzer" dans l'UI avec sélecteur GPIO exclusif, toggle et slider de volume.
    [app.js, audio_manager.cpp, config.h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]
